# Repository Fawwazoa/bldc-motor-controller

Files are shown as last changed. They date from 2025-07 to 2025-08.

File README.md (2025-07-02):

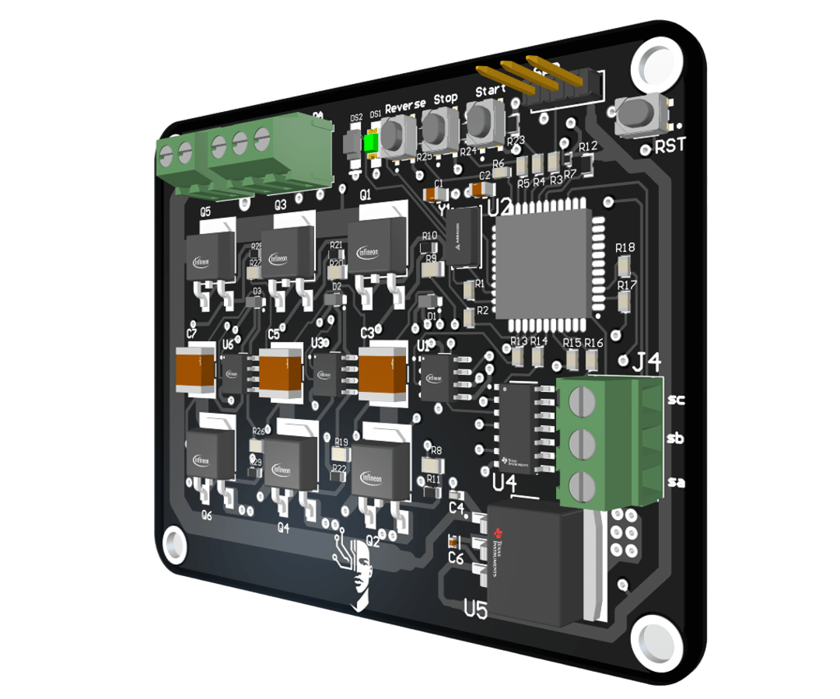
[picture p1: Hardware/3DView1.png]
PCB Layout of 3-Phase BLDC Controller

# 3-Phase BLDC Motor Controller (ESC)

Open Hardware & Firmware for a **Hall-sensor-based 6-step BLDC motor controller** using **PIC18F**.

---

## 📌 Project Overview

This project implements a **3-phase BLDC motor controller** using Hall sensor-based 6-step commutation with PWM speed control. The system uses a **PIC18F46K22 microcontroller** and IR2101 gate drivers for driving the MOSFET bridge.

---

## 🛠 Features

* ✅ 3-phase BLDC control using 6-step commutation
* ✅ Speed control using analog potentiometer (ADC) with PWM
* ✅ Direction control with REVERSE button
* ✅ Start/Stop functionality
* ✅ LED indicators for direction status
* ✅ Open Hardware under CERN OHL v2 license

---

---

## ⚙️ Hardware

* **Microcontroller:** PIC18F46K22
* **Gate Driver:** IR2101
* **MOSFETs:** IRF540N or IRFZ44N
* **Sensors:** Hall sensors for rotor position
* **PCB:** 4-layer (2 signal, 2 GND planes)
* **Simulation:** Proteus for pre-validation
* **CAD:** Altium Designer for schematic and layout

---

## 🔧 Firmware

* Developed in CCS C for the PIC18F46K22.
* Uses interrupts for Hall sensor capture and commutation lookup table.
* ADC reads potentiometer voltage to control PWM duty cycle.
* PWM generated for speed control.

---

## 🛡️ Licensing

This hardware project is licensed under the **CERN Open Hardware License v2 (CERN OHL v2)**.  
See the [LICENSE](LICENSE) file for details.

---

## 🤝 Contributing

* ✅ This project is open for modifications, and improvements.
* ✅ Pull requests and hardware validation feedback are welcome.
* ✅ Please credit if you use this design in your projects.

---

## 📸 Preview

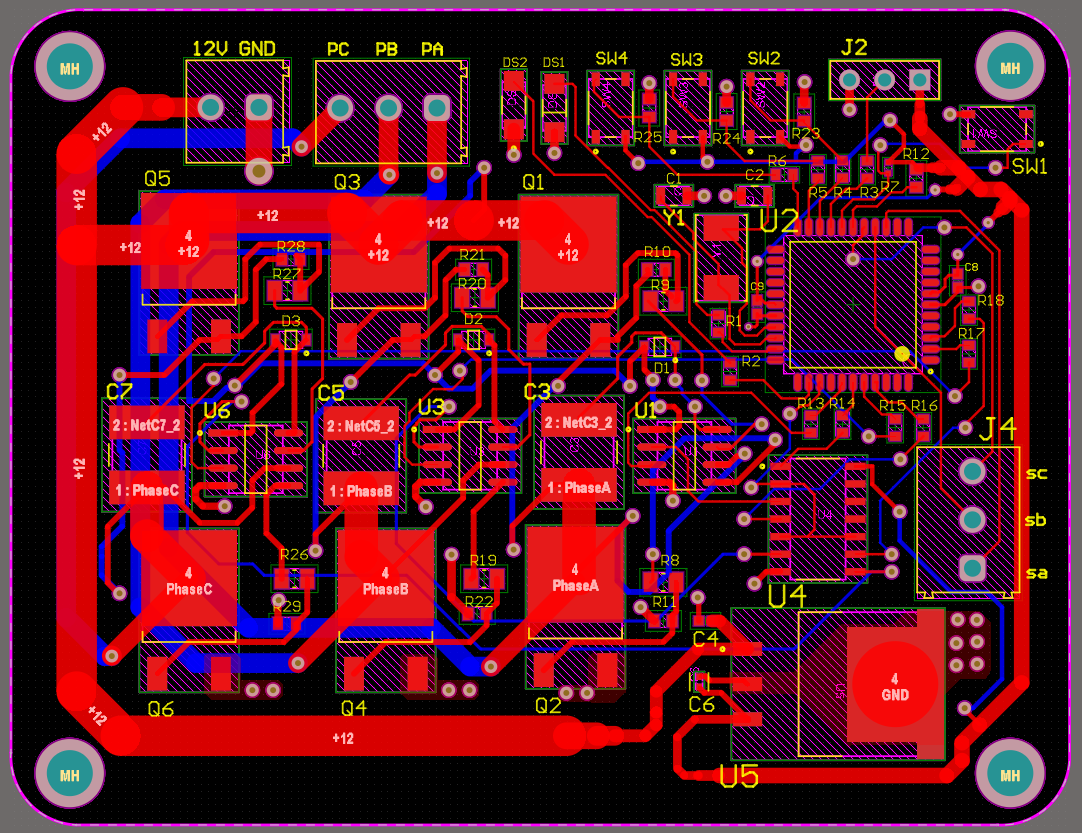
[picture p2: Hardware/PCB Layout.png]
PCB Layout


---

## 📫 Contact

If you have suggestions or questions feel free to contact.
- 📧 Email: fawazyousifabkr00@gmail.com
- 🛠 [My Hackaday Profile](https://hackaday.io/Fawwazoa)

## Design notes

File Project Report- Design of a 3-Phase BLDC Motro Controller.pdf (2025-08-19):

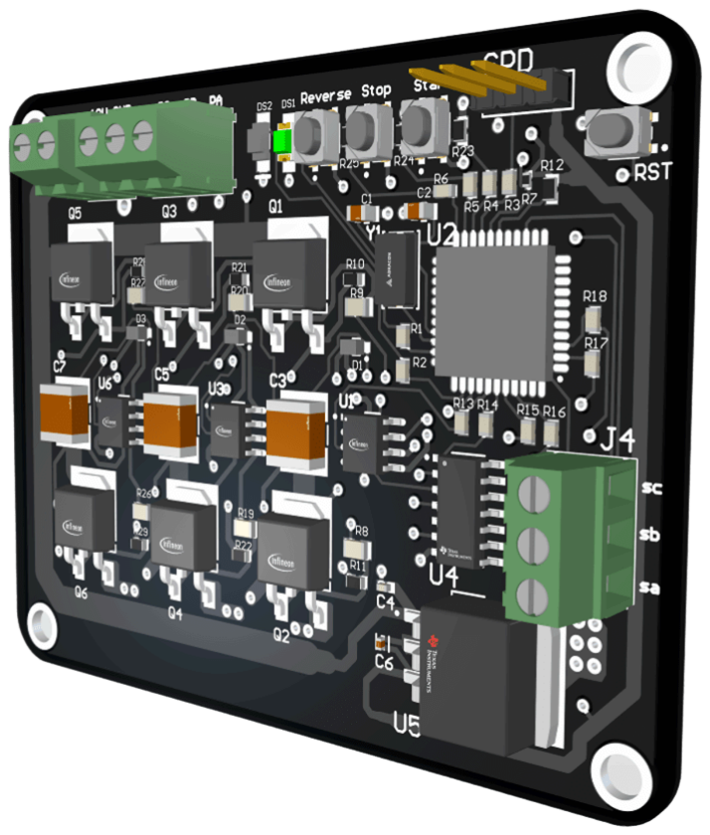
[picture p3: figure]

# Design of a 3-Phase BLDC Motor Controller

28.06.2025
─

## Fawaz Yousif

## Overview

This project idea was simulating and designing a 3-phase Brushless DC (BLDC) motor controller , also known as an ESC(Electronic Speed Controller), using a PIC18F microcontroller with IR2101 gate drivers and Hall-sensor-based 6-step commutation. The objective is to control the speed and direction of a BLDC motor using PWM for speed modulation and logic switching for phase control, all simulated and verified in Proteus before hardware implementation.

The system accepts potentiometer input to vary motor speed and uses START, STOP, and REVERSE buttons for user control, aiming for a customizable, low-cost controller suitable for robotics and small vehicle applications.

## Theoretical Explanation

How does a BLDC Motor work?

A Brushless DC (BLDC) motor is a synchronous electric motor that uses electronic commutation instead of mechanical brushes and a commutator. Its structure mainly consists of both the Rotor, which is the rotating permanent magnet part, and the Stator, which is the stationary part that is formed by the 3-phase windings.

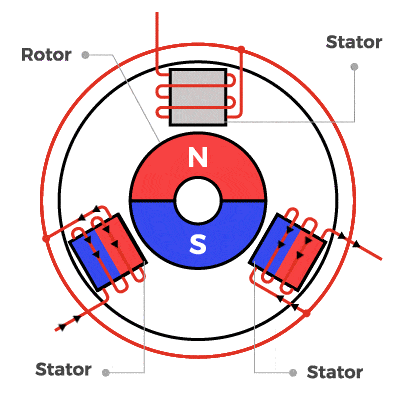
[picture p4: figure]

Figure 1: BLDC Motor Structure

Source: espressif.com

Principle of Operation:

Initially the stator windings are energized in a specific sequence to produce a rotating magnetic field. Then the permanent magnet rotor follows the rotating field, creating mechanical rotation. Unlike AC induction motors, BLDC motors use rotor position feedback (Hall sensors) to control commutation precisely. The sequence of energizing the stator is controlled by what is called a 6-step commutation.

What is a 6-step Commutation?

In a 6-step commutation, one electrical cycle is divided into six steps, each 60° apart. At each step two out of three phases are energized (one high, one low) and the third phase is left floating. This eventually produces a rotating magnetic field, pulling the rotor forward.

Step | Hall Sensors | Phases Energized
A | B | C
1 | 1 | -1 | 0 | A+, B-
2 | 1 | 0 | -1 | A+, C-
3 | 0 | 1 | -1 | B+, C-
4 | -1 | 1 | 0 | A-, B+
5 | -1 | 0 | 1 | C+, A-
6 | 0 | -1 | 1 | B-, C+

Table 1: Sequence of the 6-Step Commutation

The sequence of energizing phases is determined by reading the Hall sensor signals, which indicate the rotor position in real-time. What if we would like to control the speed of the motor? Here comes what is known as a PWM.

What is a PWM?

PWM or Pulse Width Modulation is a signal generated by the microcontroller to control the speed of the motor. By adjusting the "on" time (duty cycle) of the pulses, the controller effectively changes the perceived voltage, thereby controlling the motor's speed. A higher duty cycle Increases the average voltage applied to the motor, resulting in higher speed.

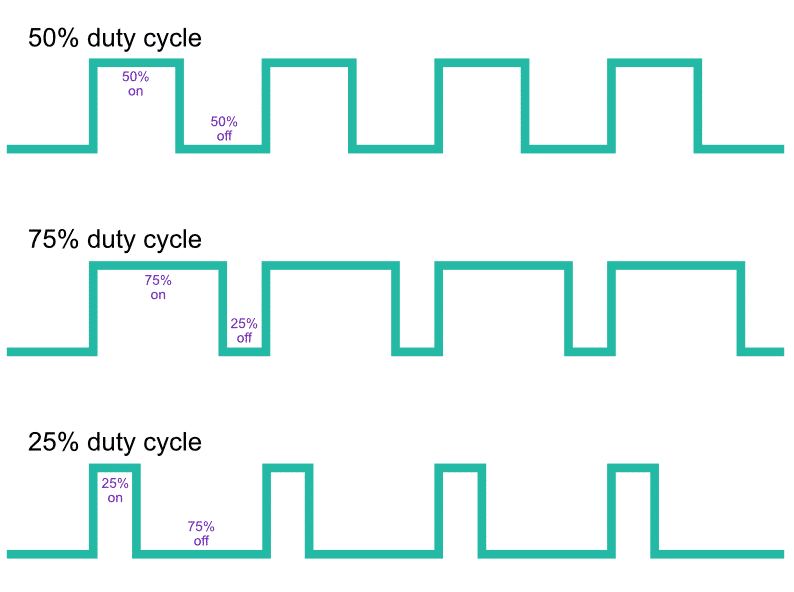
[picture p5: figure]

Figure 2: Example of PWM Signals with Their Duty Cycles

## Simulation

Proteus was used to simulate the full BLDC control system, as it is capable of supporting co-simulation of microcontroller firmware with hardware circuits. The simulation mainly included the PIC18F46K22, IR2101 gate drivers, MOSFET bridge, Hall sensors, and the BLDC motor model.

## Simulation Objectives

The goal of the simulation was to verify PWM generation and duty cycle variation using a virtual potentiometer. As well as Validating the six-step commutation sequence and correct phase energizing. And Confirming the response of the system to Hall sensor changes.

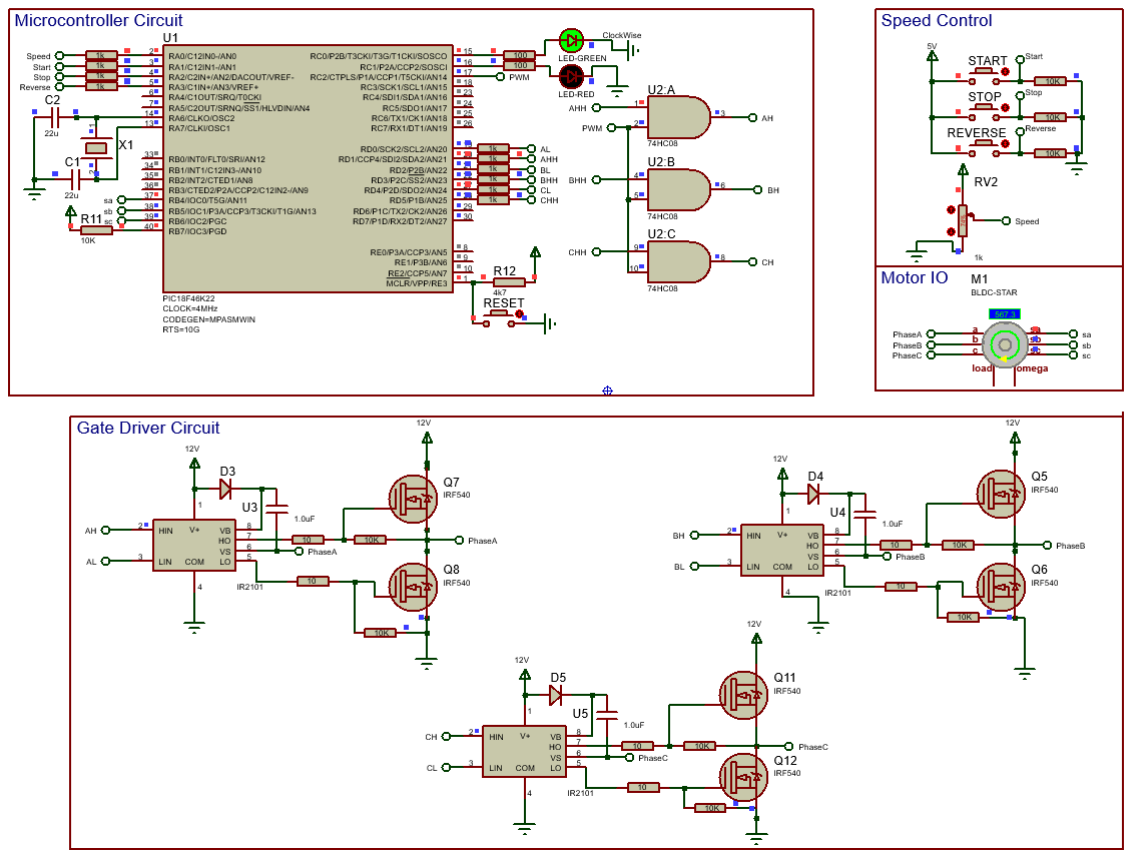
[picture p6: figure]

Figure 3: Simulation Schematic

## PIC Microcontroller Code Logic:

The code sets up the PIC18F46K22 to use PWM for speed control, ADC (Analog to Digital Converter) to read a potentiometer, and buttons to start, stop, or reverse the motor. It also prepares an interrupt that checks the Hall sensors to know the motor’s rotor position and chooses the right phases to turn on for forward or reverse rotation using lookup tables.

In the main loop, when the start button is pressed, the motor runs and LEDs show the direction. The potentiometer changes the PWM duty cycle, adjusting the motor speed. The interrupt keeps updating which motor phases to energize based on the rotor position so the motor keeps turning while the PWM controls how fast it spins.

## Electronic Design

## I. The Schematic Diagram

The electronic design has included the following:

- PIC18F46K22 microcontroller for core control logic.
- 74HC08 Logic AND gates: combine PWM with commutation signals for each phase.
- IR2101 gate drivers to drive the high-side and low-side MOSFETs.
- MOSFET bridge to control the 3-phase outputs to the BLDC motor.
- Hall-effect sensor inputs for rotor position feedback.
- Potentiometer connected to the ADC for speed control.
- Start, Stop, Reverse and Reset buttons for user interaction.
- Bootstrap capacitors, decoupling capacitors, gate resistors, and protection diodes for stability and reliability.

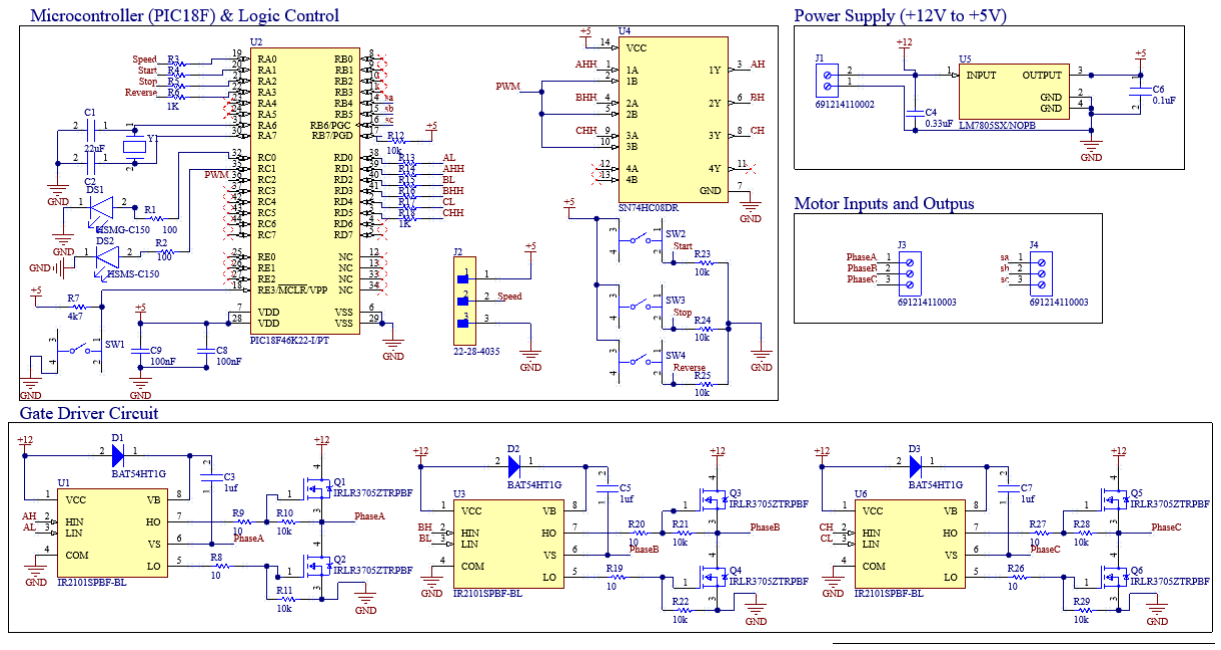
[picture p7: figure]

Figure 4: The Schematic Diagram

## II. PCB Layout

A 4-layer PCB (2 signal layers + 2 ground planes) was designed in Altium, with the consideration of a clear separation between high-current MOSFET sections and low-voltage control logic. The 2 dedicated ground planes on inner layers minimize noise, reduce EMI, and improve signal integrity for PWM and Hall signals.

Another consideration has been taken into account is the wide power traces for +12V and ground to handle motor currents safely. Also decoupling capacitors have been considered to be positioned near the MCU and gate drivers to maintain stable operation.

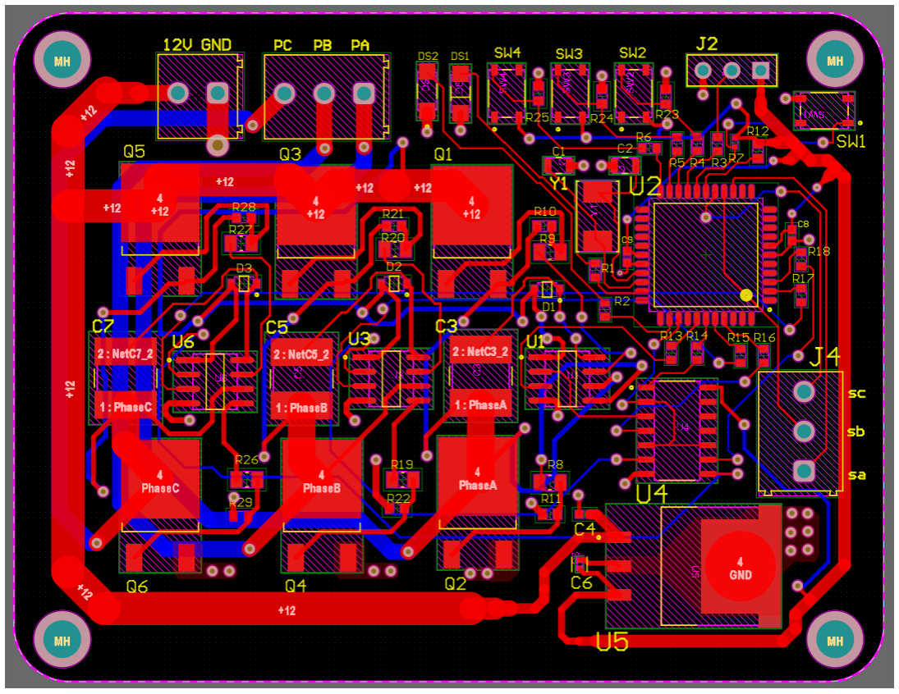
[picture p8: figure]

Figure 5: 2d View of the PCB Layout

## Project Repository and Profile Links

This project is open source hardware, and you can access its firmware and hardware files through the following links:

- 🔗 GitHub Repository: https://github.com/Fawwazoa/bldc-motor-controller (Contains firmware code, schematic, PCB layout, BOM, and project documentation)
- 🔗 My Hackaday Profile: hackaday.io/Fawwazoa
(For project logs, community discussions, and build updates.)

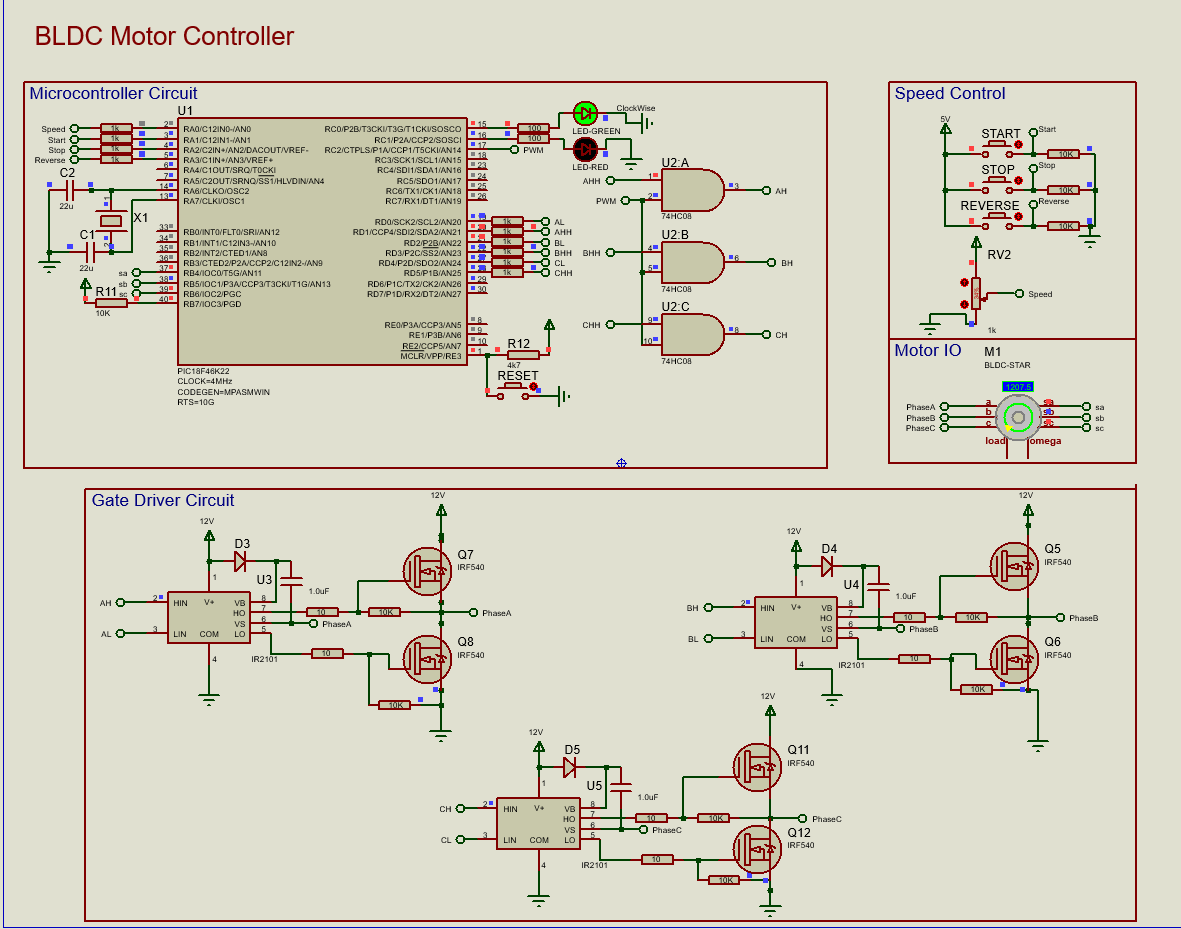
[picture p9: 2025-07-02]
Simulation/Simulation ScreenShot.png

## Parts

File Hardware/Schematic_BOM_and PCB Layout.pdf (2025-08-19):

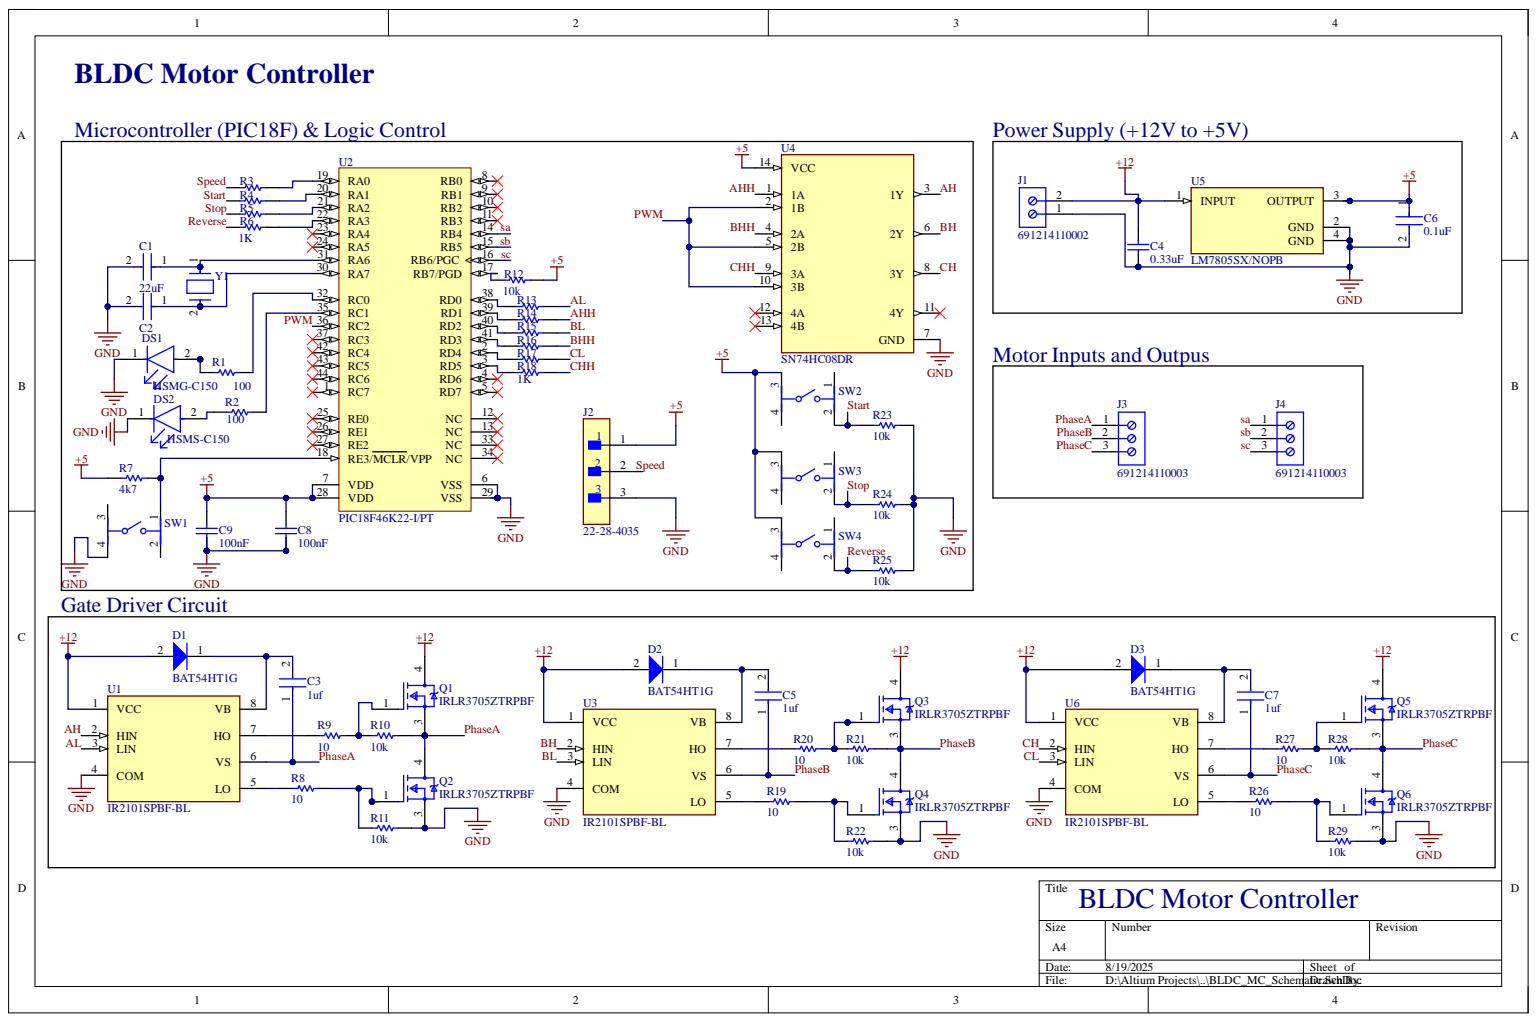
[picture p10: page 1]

Motor Inputs and Outpus

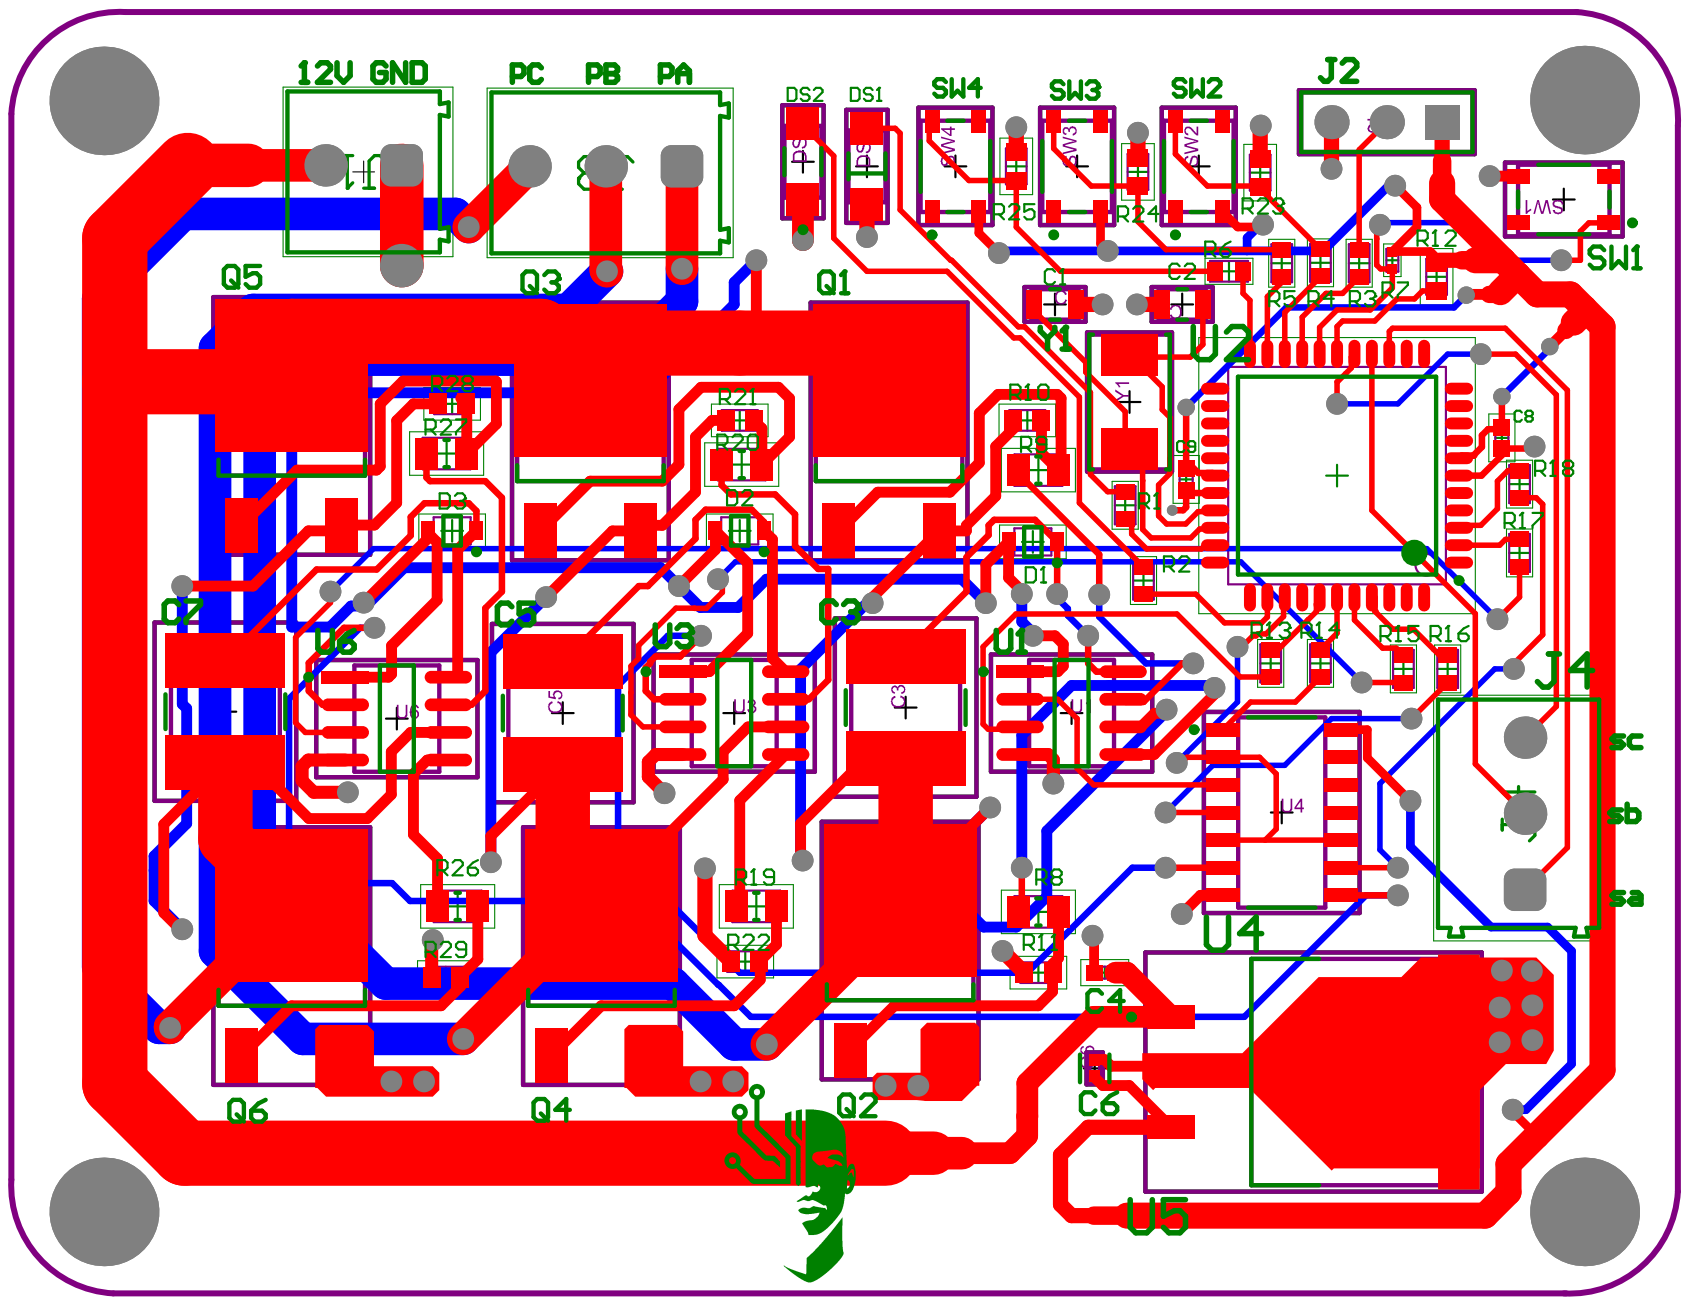
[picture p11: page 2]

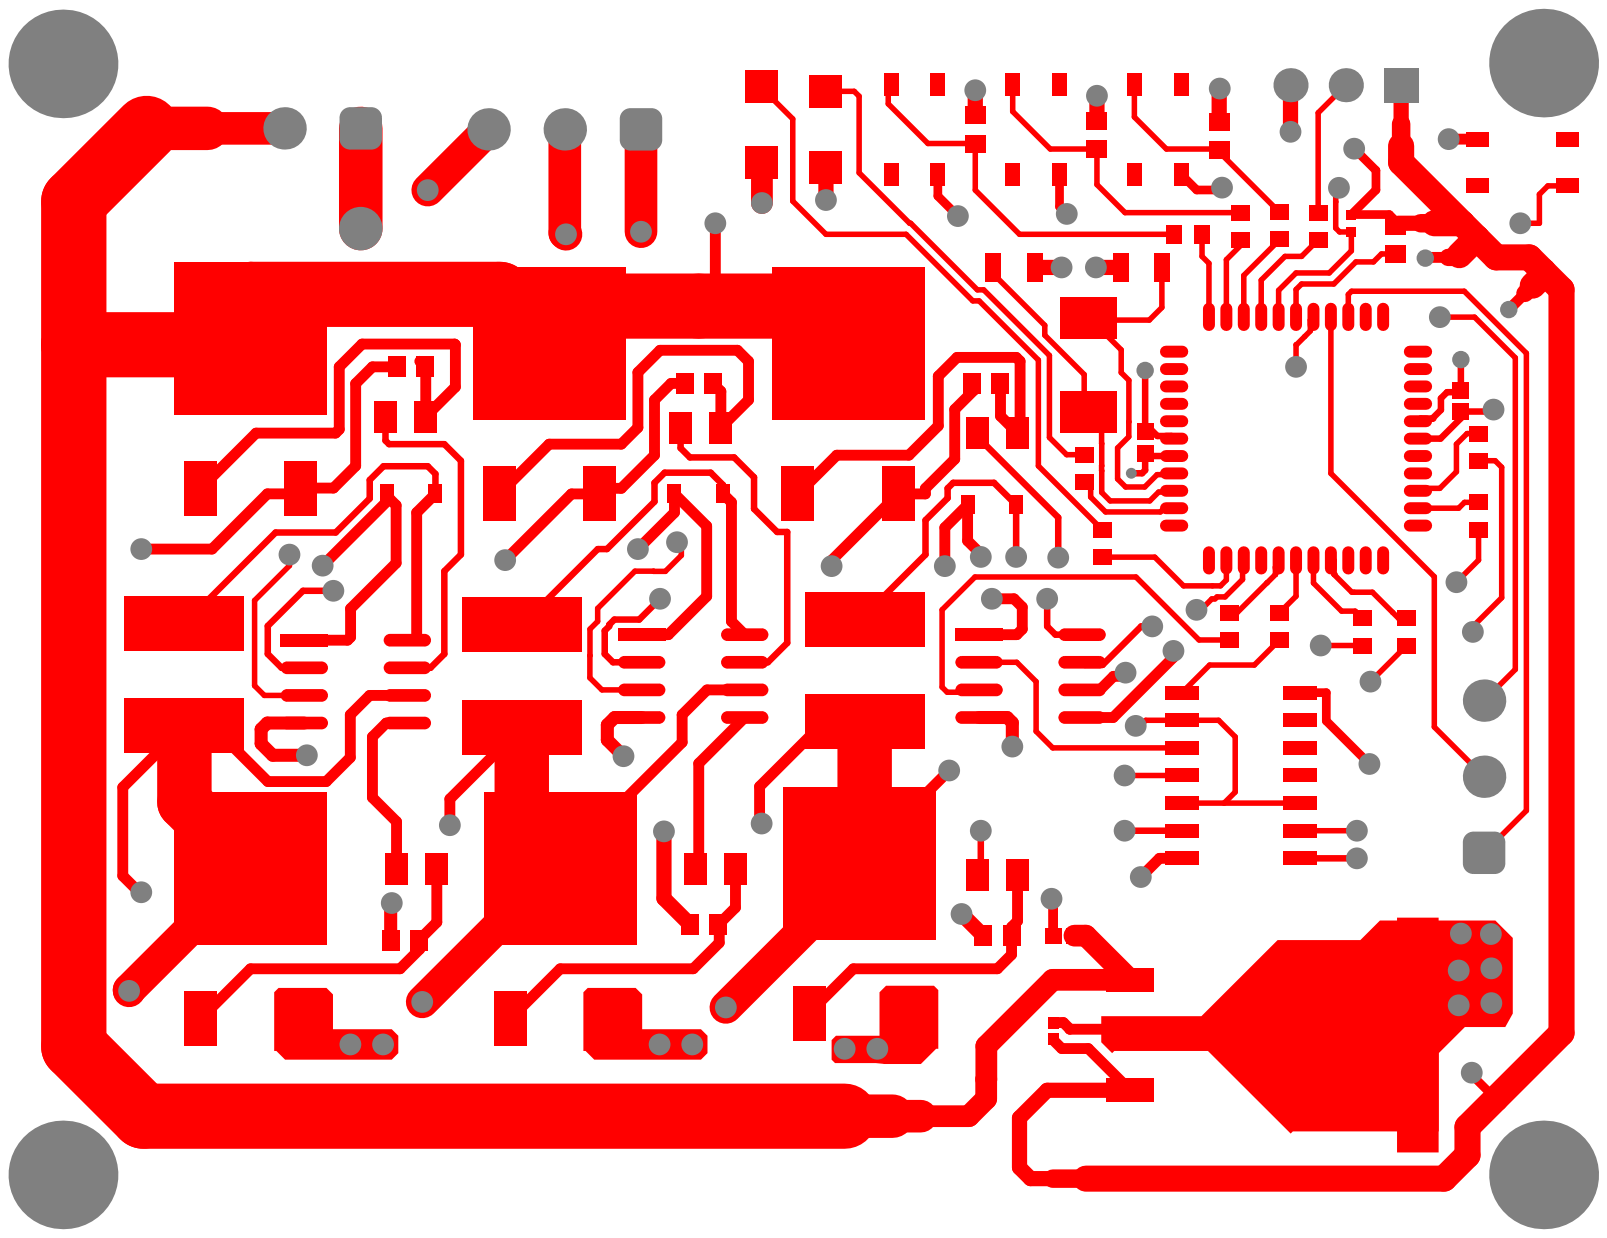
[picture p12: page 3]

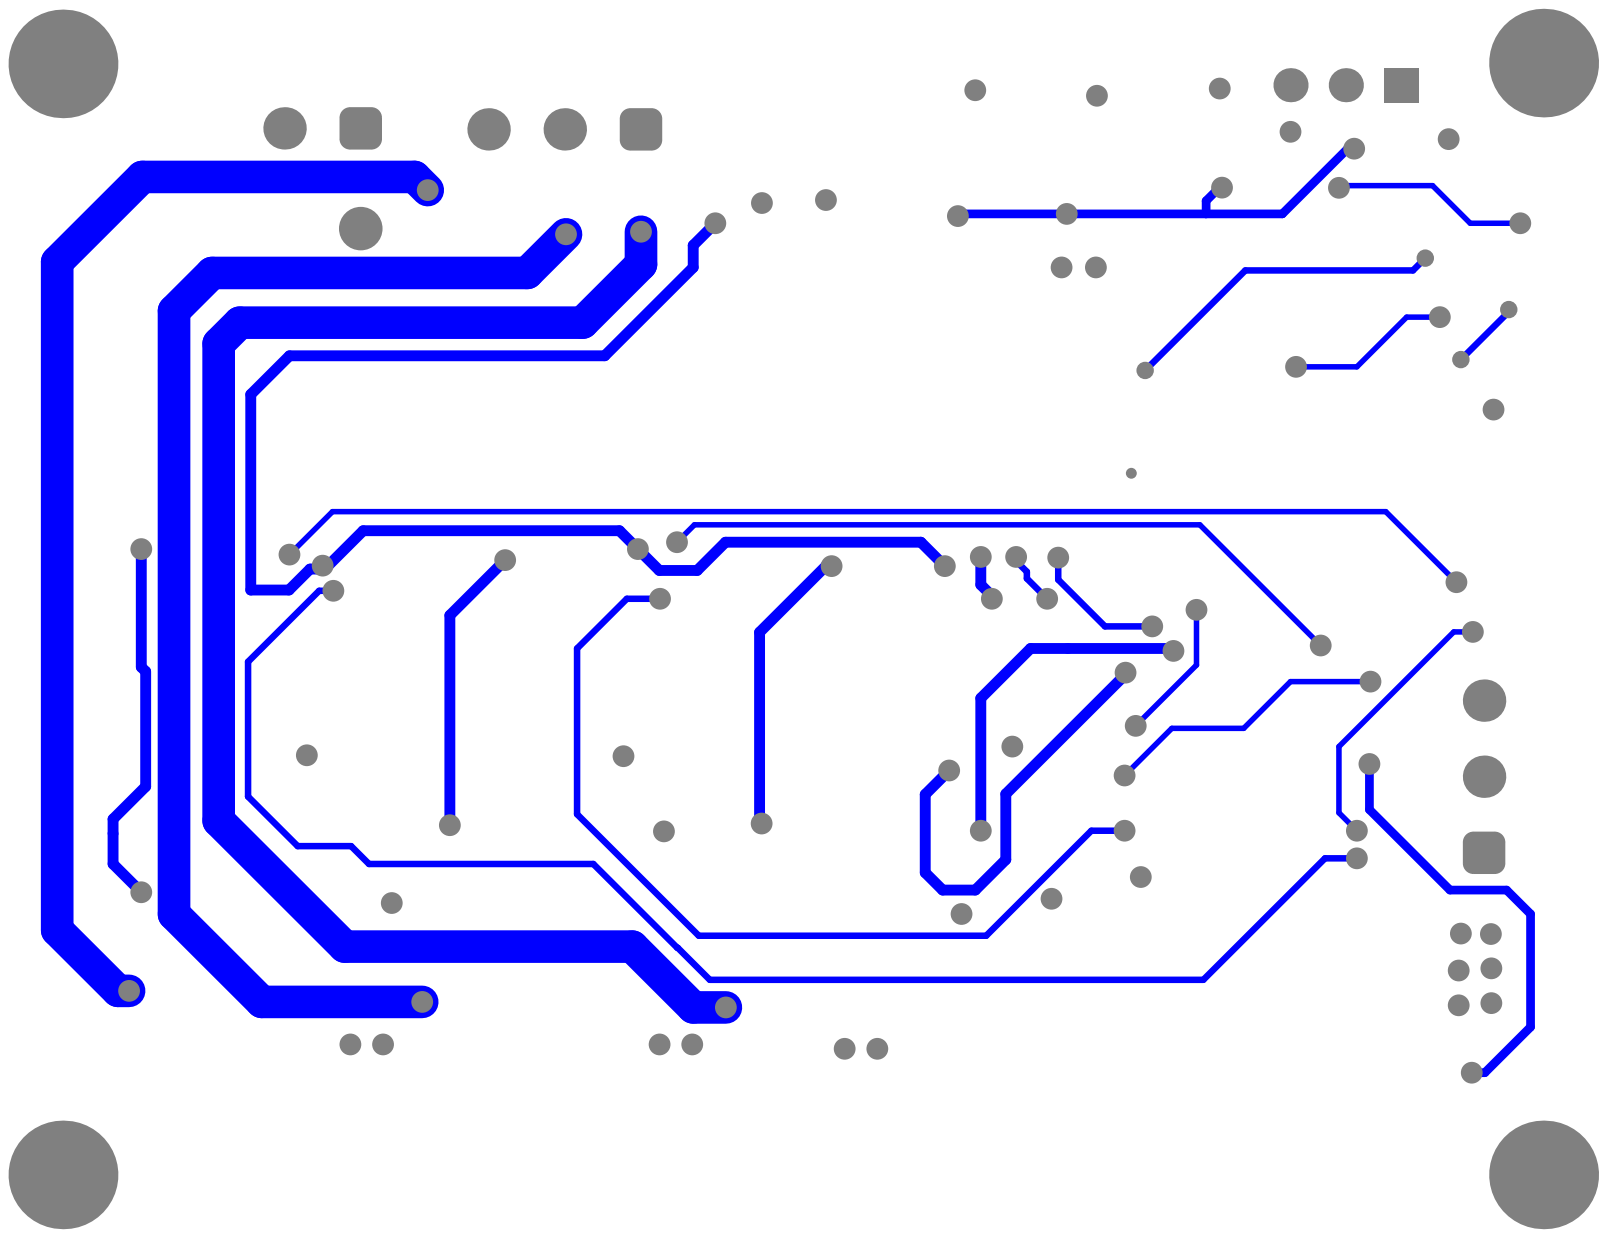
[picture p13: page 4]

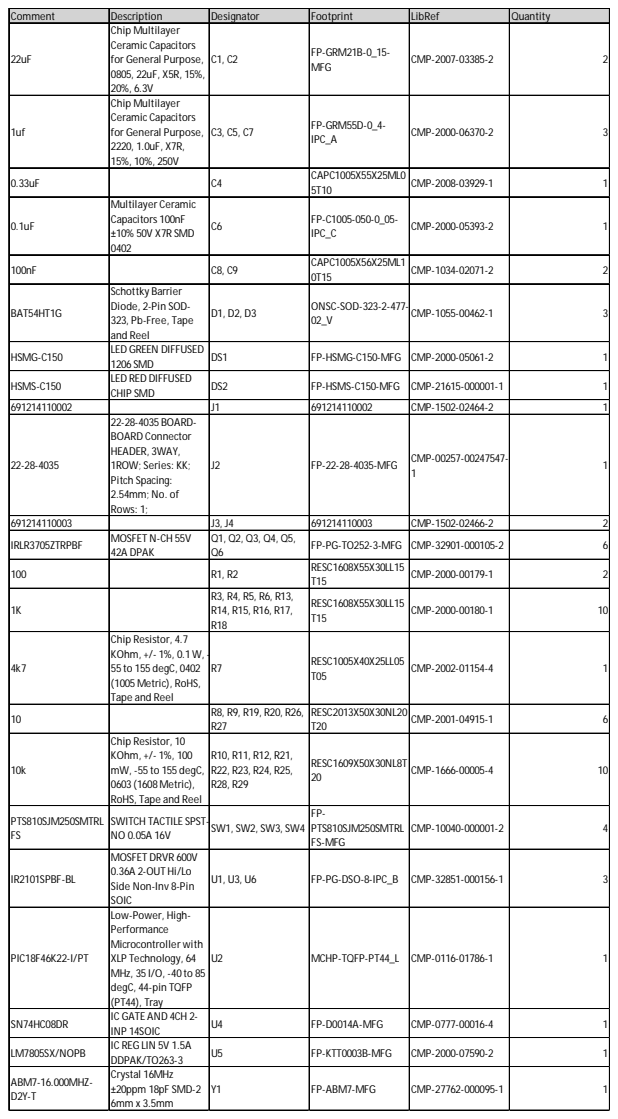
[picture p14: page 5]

Comment | Description | Designator | Footprint | LibRef | Quantity
22uF | Chip Multilayer Ceramic Capacitors for General Purpose, 0805, 22uF, X5R, 15%, 20%, 6.3V | C1, C2 | FP-GRM21B-0_15-MFG | CMP-2007-03385-2 | 2

1uf | Chip Multilayer Ceramic Capacitors for General Purpose, 2220, 1.0uF, X7R, 15%, 10%, 250V | C3, C5, C7 | FP-GRM55D-0_4-IPC_A | CMP-2000-06370-2 | 3

0.33uF | | C4 | CAPC1005X55X25ML0 5T10 | CMP-2008-03929-1 | 1

0.1uF | Multilayer Ceramic Capacitors 100nF ±10% 50V X7R SMD 0402 | C6 | FP-C1005-050-0_05-IPC_C | CMP-2000-05393-2 | 1

100nF | | C8, C9 | CAPC1005X56X25ML1 0T15 | CMP-1034-02071-2 | 2

BAT54HT1G | Schottky Barrier Diode, 2-Pin SOD-323, Pb-Free, Tape and Reel | D1, D2, D3 | ONSC-SOD-323-2-477-02_V | CMP-1055-00462-1 | 3

HSMG-C150 | LED GREEN DIFFUSED 1206 SMD | DS1 | FP-HSMG-C150-MFG | CMP-2000-05061-2 | 1

HSMS-C150 | LED RED DIFFUSED CHIP SMD | DS2 | FP-HSMS-C150-MFG | CMP-21615-000001-1 | 1

691214110002 | | J1 | 691214110002 | CMP-1502-02464-2 | 1
22-28-4035 | 22-28-4035 BOARD-BOARD Connector HEADER, 3WAY, 1ROW; Series: KK; Pitch Spacing: 2.54mm; No. of Rows: 1; | J2 | FP-22-28-4035-MFG | CMP-00257-00247547-1 | 1

691214110003 | | J3, J4 | 691214110003 | CMP-1502-02466-2 | 2
IRLR3705ZTRPBF | MOSFET N-CH 55V 42A DPAK | Q1, Q2, Q3, Q4, Q5, Q6 | FP-PG-TO252-3-MFG | CMP-32901-000105-2 | 6

100 | | R1, R2 | RESC1608X55X30LL15 T15 | CMP-2000-00179-1 | 2

1K | | R3, R4, R5, R6, R13, R14, R15, R16, R17, R18 | RESC1608X55X30LL15 T15 | CMP-2000-00180-1 | 10

4k7 | Chip Resistor, 4.7 KOhm, +/- 1%, 0.1 W, -55 to 155 degC, 0402 (1005 Metric), RoHS, Tape and Reel | R7 | RESC1005X40X25LL05 T05 | CMP-2002-01154-4 | 1

10 | | R8, R9, R19, R20, R26, R27 | RESC2013X50X30NL20 T20 | CMP-2001-04915-1 | 6

10k | Chip Resistor, 10 KOhm, +/- 1%, 100 mW, -55 to 155 degC, 0603 (1608 Metric), RoHS, Tape and Reel | R10, R11, R12, R21, R22, R23, R24, R25, R28, R29 | RESC1609X50X30NL8T 20 | CMP-1666-00005-4 | 10

PTS810SJM250SMTRL FS | SWITCH TACTILE SPST-NO 0.05A 16V | SW1, SW2, SW3, SW4 | FP-PTS810SJM250SMTRL FS-MFG | CMP-10040-000001-2 | 4

IR2101SPBF-BL | MOSFET DRVR 600V 0.36A 2-OUT Hi/Lo Side Non-Inv 8-Pin SOIC | U1, U3, U6 | FP-PG-DSO-8-IPC_B | CMP-32851-000156-1 | 3

PIC18F46K22-I/PT | Low-Power, High-Performance Microcontroller with XLP Technology, 64 MHz, 35 I/O, -40 to 85 degC, 44-pin TQFP (PT44), Tray | U2 | MCHP-TQFP-PT44_L | CMP-0116-01786-1 | 1

SN74HC08DR | IC GATE AND 4CH 2-INP 14SOIC | U4 | FP-D0014A-MFG | CMP-0777-00016-4 | 1

LM7805SX/NOPB | IC REG LIN 5V 1.5A DDPAK/TO263-3 | U5 | FP-KTT0003B-MFG | CMP-2000-07590-2 | 1

ABM7-16.000MHZ-D2Y-T | Crystal 16MHz ±20ppm 18pF SMD-2 6mm x 3.5mm | Y1 | FP-ABM7-MFG | CMP-27762-000095-1 | 1

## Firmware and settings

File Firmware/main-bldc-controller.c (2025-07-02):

#include <18F46k22.h> 
#device ADC=10        // ADC resolution is defined as 10 bit
#use delay(crystal=8000000) // Clock speed defined for microcontroller

#use FIXED_IO(C_outputs=PIN_C2,PIN_C1,PIN_C0) // PIN_C2 and PIN_C0 Configured as output


#use fast_io(C) // C port is defined as fast io

#use fast_io(D) // D port is defined as fast io

#define START_BUTTON pin_a1
#define STOP_BUTTON pin_a2
#define REVERSE_BUTTON pin_a3
#define LED_GREEN pin_c0
#define LED_RED pin_c1

int16 duty=0; // Holds the PWM duty cycle value.
const int bldc_move_table[8]    = {0, 18, 9, 24, 36, 6, 33, 0};
const int bldc_move_table_rev[8]= {0, 33, 6, 36, 24, 9, 18, 0};

int hall_input=0, rev=0, run=0; // Track rotor position, direction, and running state.
#INT_RB
void RB_isr(void)
{
    hall_input=(input_b()>>4) & 7;  // Reads RB7:RB4 as Hall sensor input (3-bit).
    if(rev==0) // If rev = 0 Motor rotation is clockwise
    {
        output_d(bldc_move_table[hall_input]); // Apply required instruction
    }
    else // Else Motor rotation is counter clockwise
    {
        output_d(bldc_move_table_rev[hall_input]); // Apply required instruction
    }
}

void main()
{
    set_tris_a(0b00001111); // Configure A7,A6,A5,A4 as output and A3,A2,A1,A0 as input
    set_tris_b(0xf0);       // Configure B7,B6,B5,B4 as input and B3,B2,B1,B0 as output
    set_tris_c(0x00);       // Configure PORTC as output
    set_tris_d(0x00);       // Configure PORTD as output

    setup_adc_ports(sAN0);  // Set AN0 channel as analog output
    setup_adc(ADC_CLOCK_INTERNAL|ADC_TAD_MUL_0); // ADC configuration
    set_adc_channel(0);     // Selecting adc conversion source

    delay_us(20);           // For acquisition time
    
    
    setup_timer_2(T2_DIV_BY_16,249,1); // 2 ms overflow, 2ms interrupt or 500Hz

    setup_ccp1(CCP_PWM|CCP_SHUTDOWN_AC_L|CCP_SHUTDOWN_BD_L); // CCP1 Configured as PWM output
    set_pwm1_duty((int16)0); // PWM duty is set at 0

    disable_interrupts(INT_RB); // Interrupt is passive
    enable_interrupts(GLOBAL);

    while(TRUE)
    {
        if(input(START_BUTTON))
        {
            if(run==0) // Check if motor already running
            {
                run=1;
                enable_interrupts(INT_RB); // Interrupt is active
                hall_input=(input_b()>>4) & 7; // First rotor position

                if(rev==0) // If motor not rotating in reverse direction
                {
                    output_low(LED_RED);     // Red light off
                    output_high(LED_GREEN);  // Green light on
                    output_d(bldc_move_table[hall_input]);
                }
                if(rev==1)
                {
                    output_low(LED_GREEN);   // Green light off
                    output_high(LED_RED);    // Red light on
                    output_d(bldc_move_table_rev[hall_input]);
                }
            }
            while(input(START_BUTTON));
        }
        else if(input(STOP_BUTTON)) // Stopping motor
        {
            disable_interrupts(INT_RB); // Interrupt disabled
            run=0;
            output_low(LED_GREEN); // Led1 off
            output_low(LED_RED);   // Led2 off
            output_d(0x00);        // Outputs off
            set_pwm1_duty((int16)0);
            while(input(STOP_BUTTON));
        }
        else if(input(REVERSE_BUTTON)) // Reversing motor direction
        {
            disable_interrupts(INT_RB); // Interrupt is passive
            if(rev==0) // If motor rotation is not reverse indicate by making rev = 1
            {
                rev=1;
                output_low(LED_GREEN); // Led1 off
                output_high(LED_RED);  // Led2 off
            }
            else // If motor rotation is already reverse indicate by making rev = 0
            {
                rev=0;
                output_low(LED_RED);   // Led1 off
                output_high(LED_GREEN);// Led2 off
            }
            run=0;
            set_pwm1_duty((int16)0);
            delay_ms(500);
            while(input(REVERSE_BUTTON));
        }

        if(run==1) // If motor is running (START_BUTTON pressed) Start Adc conversion
        {
            read_adc(ADC_START_ONLY);
            delay_us(100);
            while(!adc_done()); // Wait until conversion complete
            duty = read_adc(ADC_READ_ONLY); // Read ADC value (last value)
            duty = duty * 0.976; // 1000/1024 = 0.976
            set_pwm1_duty((int16)duty); // Set PWM duty cycle
        }
    }
}
